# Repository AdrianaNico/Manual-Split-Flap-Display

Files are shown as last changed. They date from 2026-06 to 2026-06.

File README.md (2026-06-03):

# Manual Split-Flap Display
Welcome to the Manual Split-Flap Display project! Below you can see the 3D models and the physical prototype of this fully mechanical design. **Please note that in some renders and CAD screenshots, only 2 flaps are shown for demonstration purposes to allow a clearer view of the internal mechanism. The final, complete assembly contains all 10 flaps.**

| | |
|:---:|:---:|
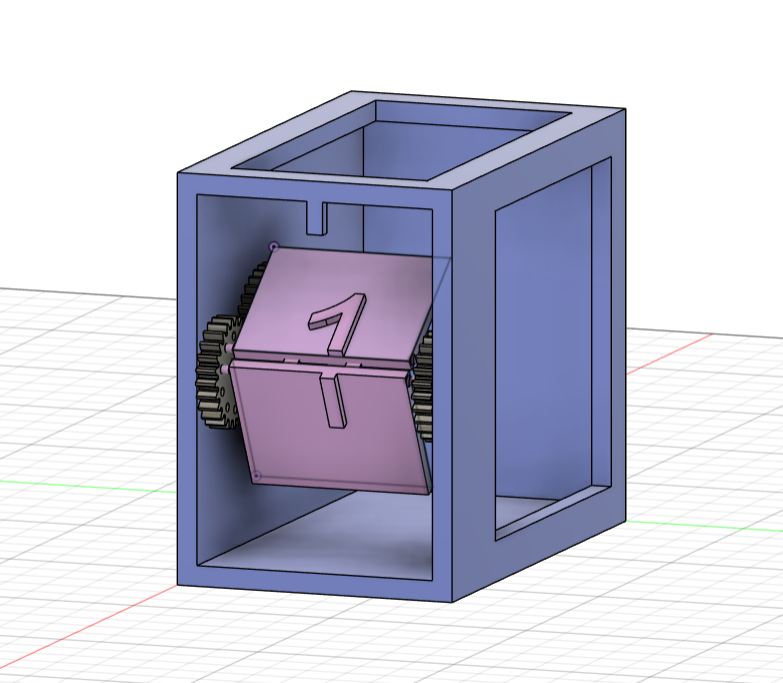
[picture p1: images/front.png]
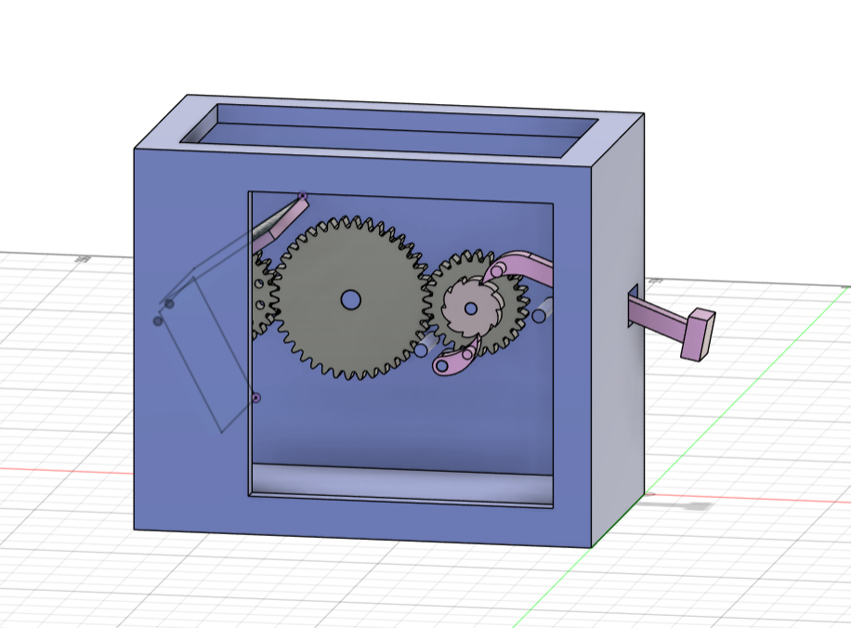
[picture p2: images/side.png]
|  |  |
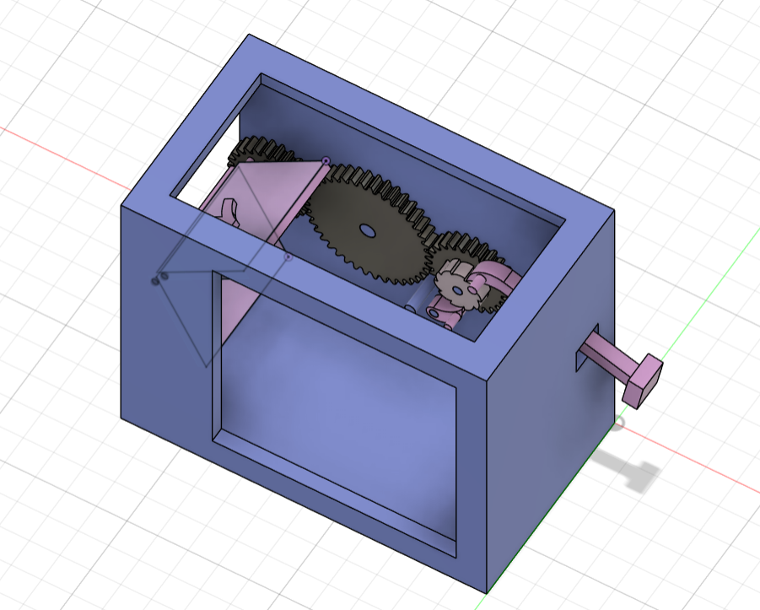
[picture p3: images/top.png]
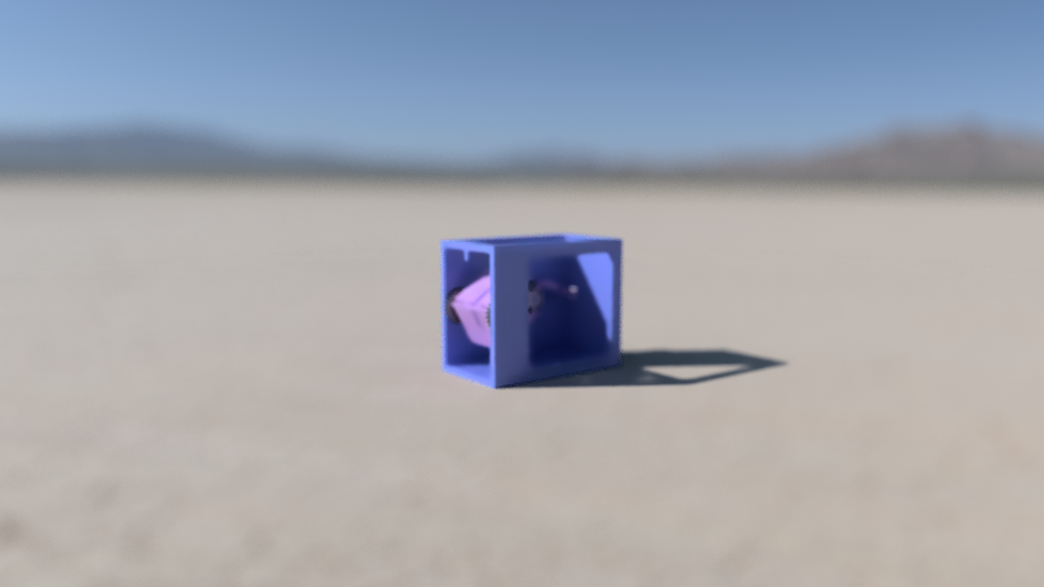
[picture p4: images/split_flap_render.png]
Split-Flap Display
|  |  |

🎥 **Project Video:** (https://youtu.be/XYKOU2_SeqI)

---

## Project Idea

This project consists of a manually operated split-flap display inspired by old train station and airport information boards.
The mechanism is designed entirely in Fusion 360 and optimized for 3D printing.
Instead of using motors or electronics, the display advances manually through a push-button mechanism that flips the next panel each time the button is pressed.

The display features:
* Numbers from 0 to 10
* A mechanical indexing and flipping system
* A compact, fully 3D printable assembly

---

## How It Works

The project uses a rotating drum containing multiple flaps. Each flap has a printed number or symbol.
When the user presses the button:
1. The kinematic mechanism rotates by a fixed angle (one full step).
2. The current flap is released from the stopper and falls forward.
3. The next number becomes visible and is locked in a perfectly vertical position.

---

## Objectives

* Design a functional split-flap mechanism in Fusion 360
* Create 3D components optimized for printing tolerances
* Implement a reliable manual step-by-step flipping mechanism
* Minimize the number of non-printable components
* Achieve precise and repeatable flap alignment

---

## Technical Details

* **Printing Material:** PETG, chosen for its mechanical wear resistance and the necessary flexibility for components under tension.
* **Project Structure (CAD):** Each component was modeled individually using a *Part Design* approach. The final project was consolidated into an *Assembly Design* to validate geometric constraints and kinematics by precisely defining motion joints.

---

## Main Components List

1. Main gear
2. Second gear
3. Third gear
4. Ratchet
5. Pawl
6. Arm button
7. Flap
8. Case

---

## Component Descriptions

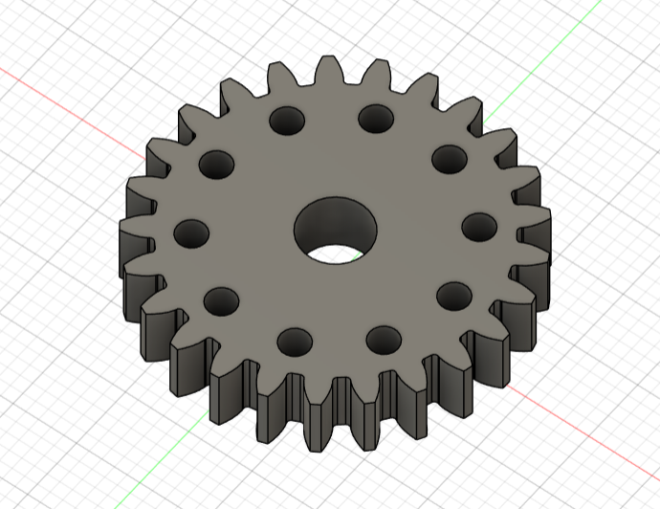
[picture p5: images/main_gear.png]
Main Gear Placeholder
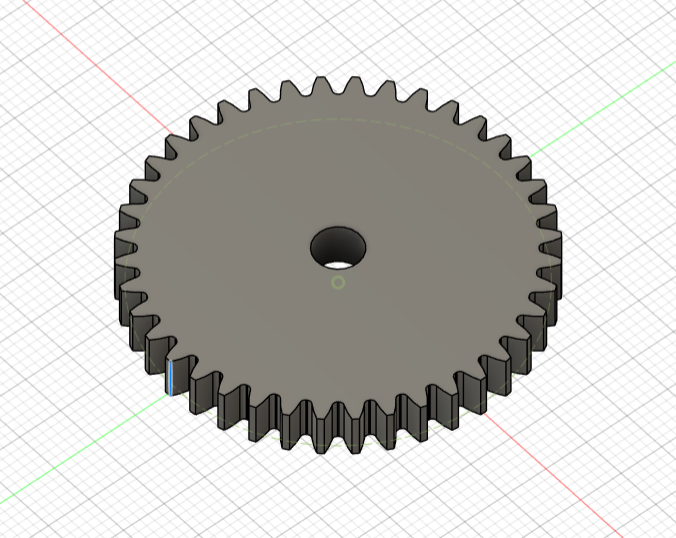
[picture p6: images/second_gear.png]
Second Gear Placeholder
|  |  |
|:---:|:---:|
| **Main Gear:** A primary gear equipped with 25 teeth for transmitting rotational motion. The structure integrates 10 radial slots spaced at equal angles, used as mounting and rotation points for the flap axes. | **Second Gear:** A 40-tooth intermediate gear responsible for transferring mechanical torque from the *third gear* to the *main gear*. The transmission ratio is strictly defined to ensure an exact 36-degree rotation per actuation (the angle required to sequentially index the 10 flaps). |

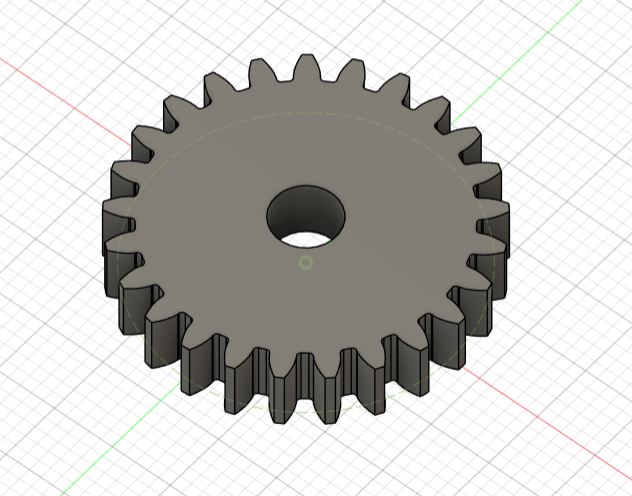
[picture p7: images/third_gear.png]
Third Gear Placeholder
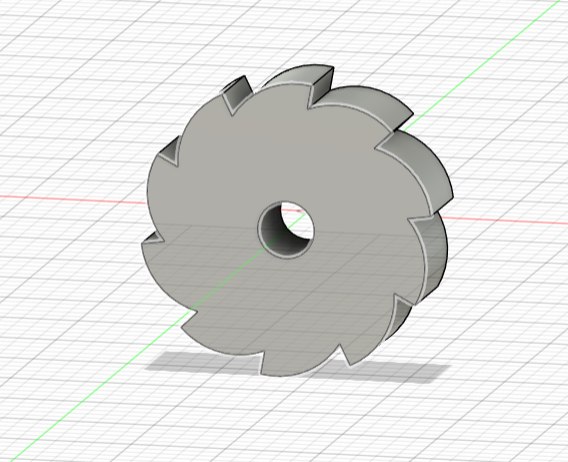
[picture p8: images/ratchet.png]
Ratchet Placeholder
|  |  |
|:---:|:---:|
| **Third Gear:** A motion take-up gear with identical specifications to the *main gear*, but with a solid structure lacking radial slots. It functions as a mounting base and provides a rigid coupling to the ratchet mechanism. | **Ratchet:** A ratchet wheel featuring asymmetrical teeth. Its kinematic role is to convert the linear motion of the actuating lever into unidirectional rotational motion. |

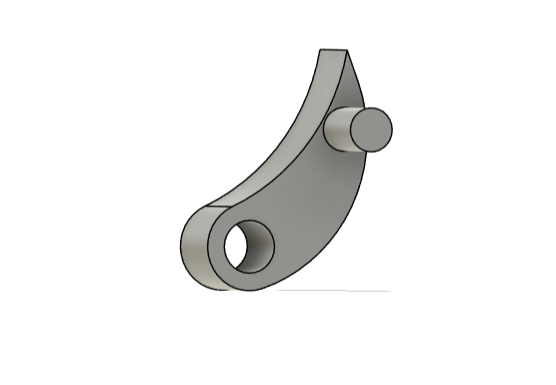
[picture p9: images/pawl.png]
Pawl Placeholder
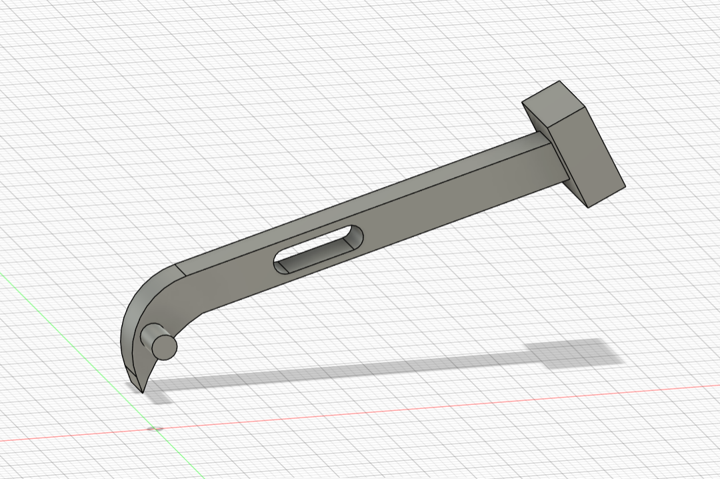
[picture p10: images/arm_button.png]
Arm Button Placeholder
|  |  |
|:---:|:---:|
| **Pawl:** A locking and retaining detent. It acts as a travel limiter for the *ratchet*, preventing over-travel and ensuring the actuating arm retracts only after reaching the optimal angle for releasing a single flap. | **Arm Button:** A linear actuating lever that includes an interactive toothed section (rack) to engage the *ratchet*. The operable end is designed as a detachable piece, allowing the shaft to pass through the guide holes in the case during assembly. |

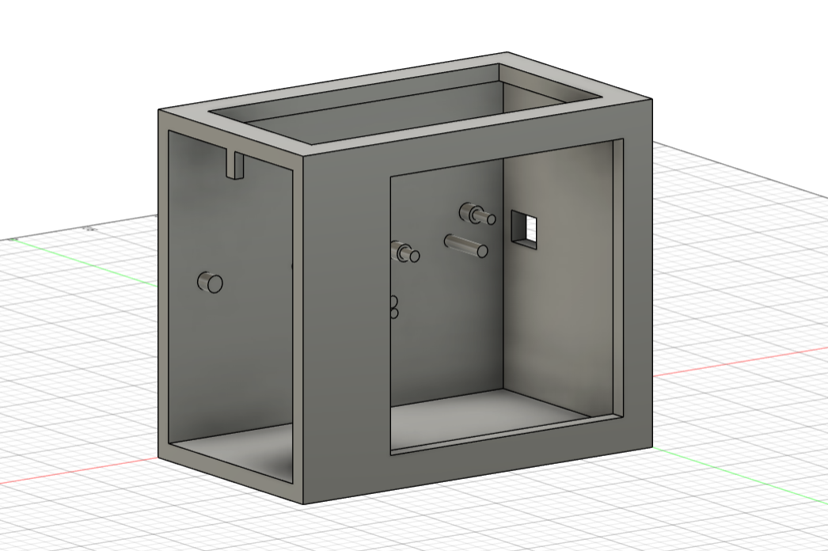
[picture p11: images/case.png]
Case Placeholder
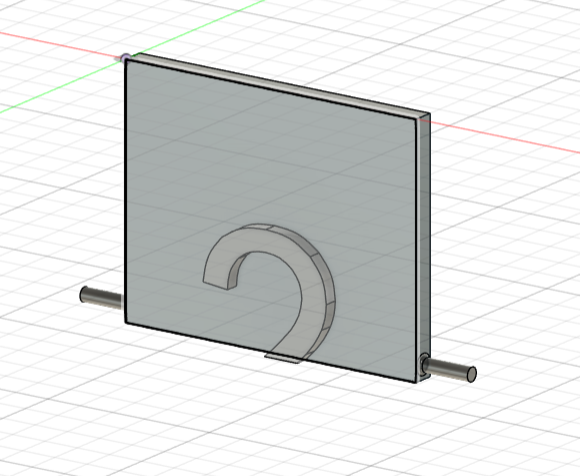
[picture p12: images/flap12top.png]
Flap Top
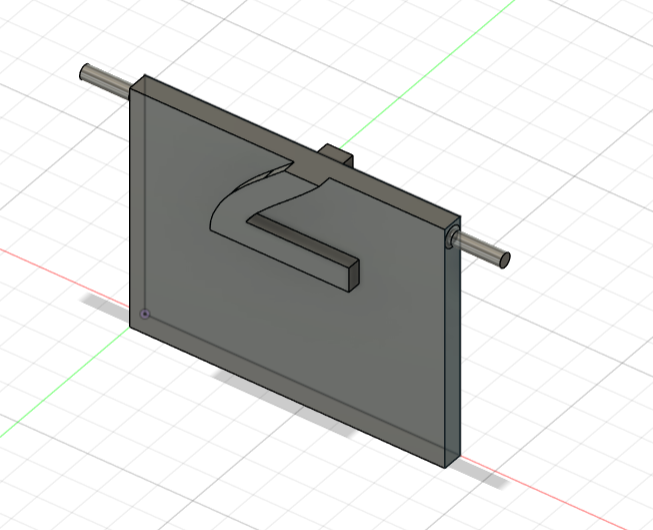
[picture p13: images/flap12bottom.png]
Flap Bottom
|  |   |
|:---:|:---:|
| **Case:** The load-bearing structure of the assembly. It integrates the bearings supporting the rotational axes of all moving parts. The design includes a geometric profile (stopper) placed in the upper section, calculated to support and lock the active flap in a vertical position. | **Flap:** A rectangular panel featuring pivots at its extremities for mechanical anchoring in the slots of the *main gear*. |

---

## Personal Touch

This project distinguishes itself from most split-flap implementations through its purely mechanical trigger approach, eliminating the reliance on electronic actuators, development boards (such as Arduino), and stepper motors found in standard models. 

The case was optimized with structural cutouts that expose the internal mechanical architecture, allowing direct observation of the gear kinematics during indexing. Furthermore, during the Fusion 360 design phase, the kinematic analysis was refined by configuring advanced motion constraints (Contact Sets and Motion Links). This allowed me to dynamically simulate the elasticity introduced by the restoring force of the tensioning rubber bands on the *pawl* system and the actuating lever.

---

## Non-Printable Objects

To complete the mechanical functionality of the system, a few external elements were required:
* **Tensioning Rubber Bands:** Small elastic bands integrated into the system to provide the necessary restoring force (return spring). They are used to bring the *arm button* back to its initial position after a press, and to maintain constant contact pressure from the *pawl* against the toothed surface of the *ratchet*.

---

## Tools Used

* Fusion 360
* GitHub
* 3D Printer
* PrusaSlicer

---

## References

* Split-flap display mechanism inspiration
* Vintage airport/train station displays
* [Fully 3D Printed Split Flap Display - Reddit](https://www.reddit.com/r/3Dprinting/comments/1jeub4g/i_designed_a_split_flap_display_fully_3d_printed/)
* [Mechanical Split Flap Inspiration - Instagram](https://www.instagram.com/p/BsODiyCHwc7/?utm_source=ig_web_copy_link&igsh=NTc4MTIwNjQ2YQ==)

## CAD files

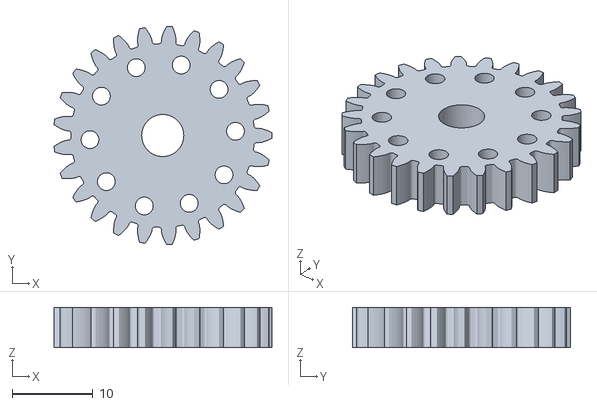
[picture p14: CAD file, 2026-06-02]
Fusion360/.stl Files/Main gear.stl
26.9 x 27.0 x 5.00

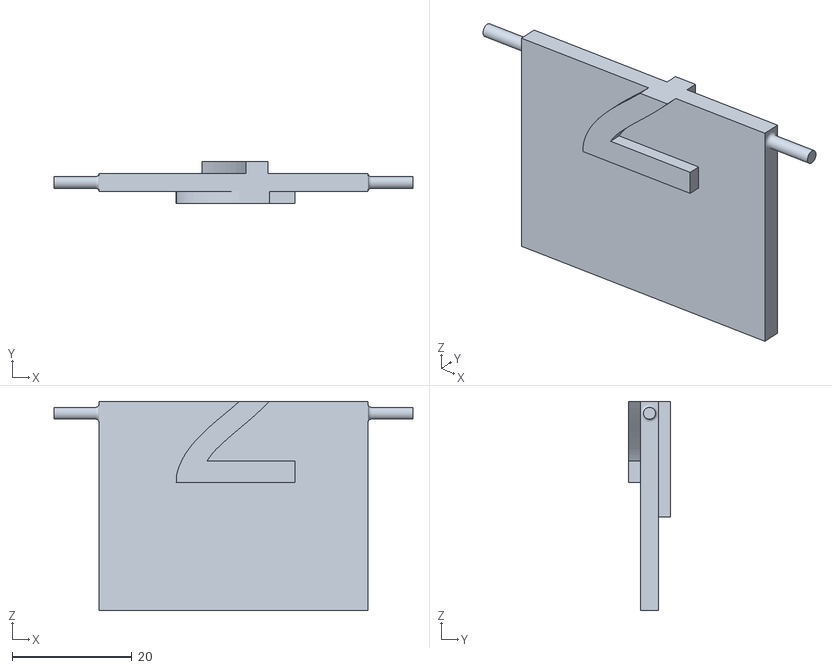
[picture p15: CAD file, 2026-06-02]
Fusion360/.stl Files/Flap12.stl
60.0 x 7.00 x 35.0

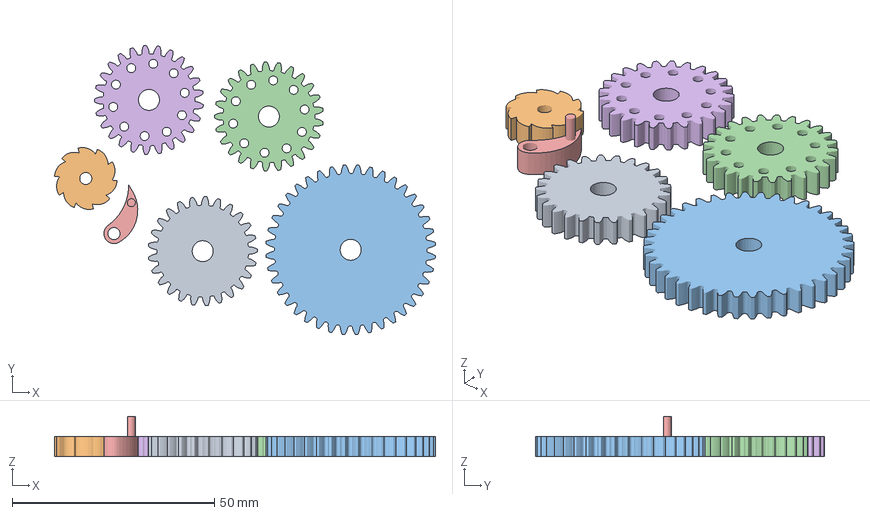
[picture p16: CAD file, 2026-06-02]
Fusion360/GCODE Files/Gears and pawl.3mf
94.2 x 71.5 x 10.0 mm
Split flap display.stl_2
Split flap display.stl_3
Split flap display.stl_4
Split flap display.stl_5
Split flap display.stl_6
Split flap display.stl_8

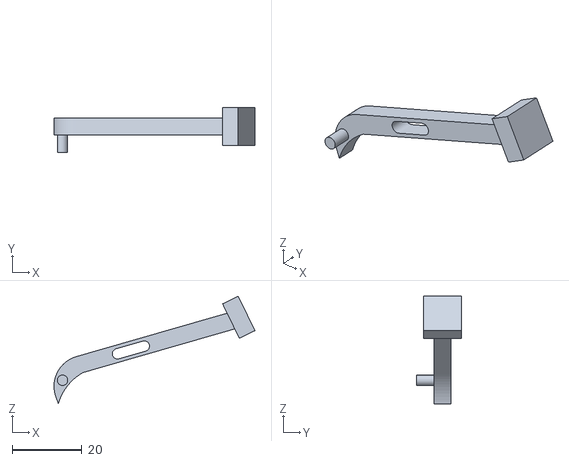
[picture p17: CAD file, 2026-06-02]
Fusion360/.stl Files/Arm button.stl
57.8 x 13.0 x 30.9

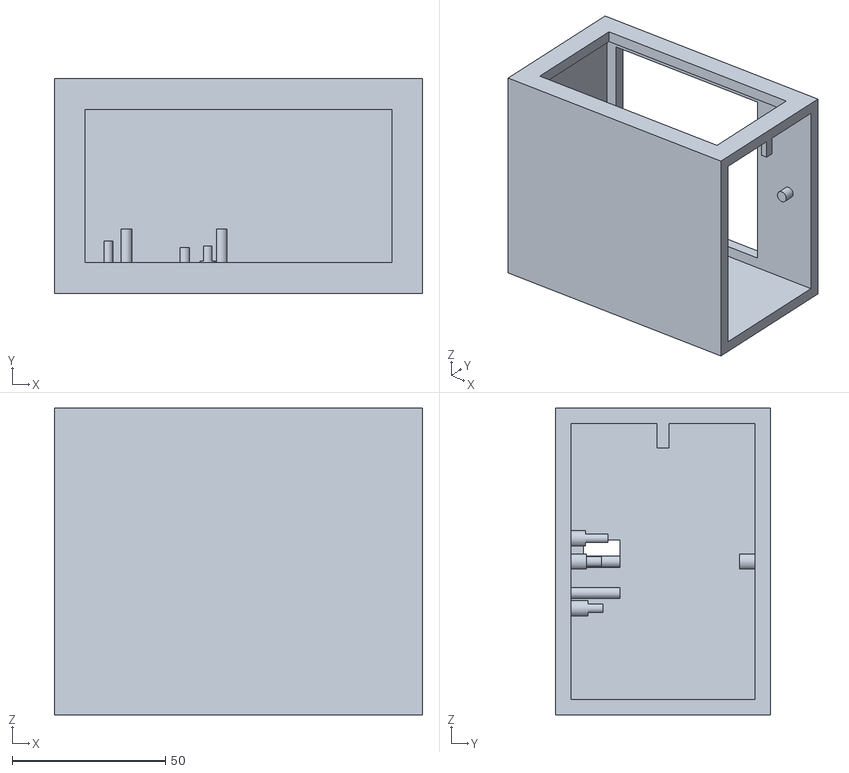
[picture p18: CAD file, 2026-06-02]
Fusion360/.stl Files/Case.stl
120.0 x 70.0 x 100.0

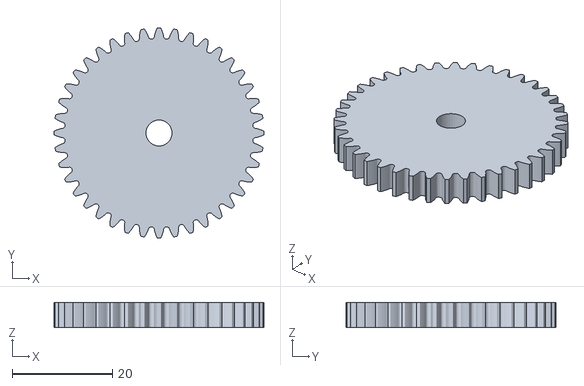
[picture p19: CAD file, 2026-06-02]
Fusion360/.stl Files/Second gear.stl
42.0 x 42.0 x 5.00

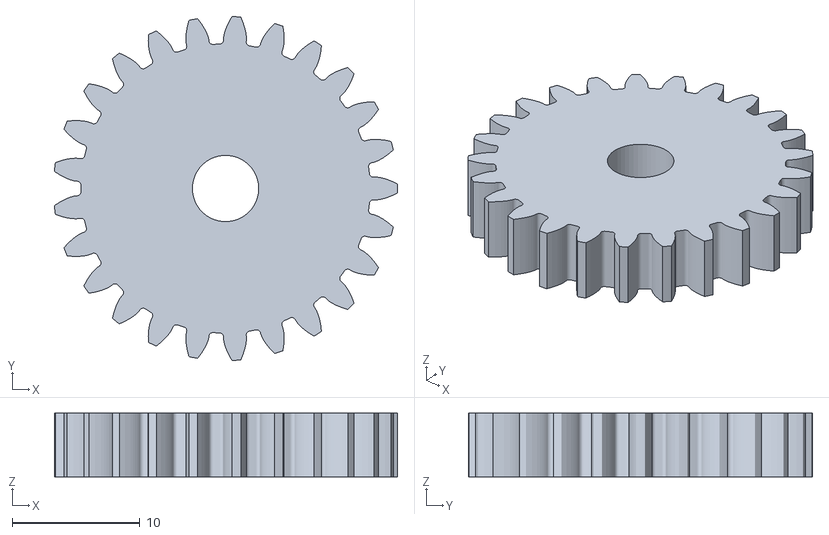
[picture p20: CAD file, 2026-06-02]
Fusion360/.stl Files/Third gear.stl
26.9 x 27.0 x 5.00

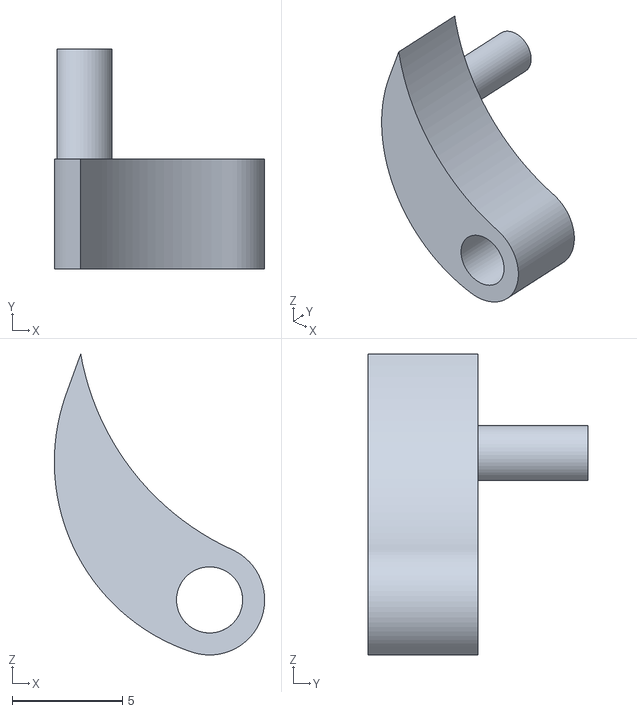
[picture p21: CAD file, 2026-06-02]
Fusion360/.stl Files/Pawl.stl
9.54 x 10.0 x 13.7

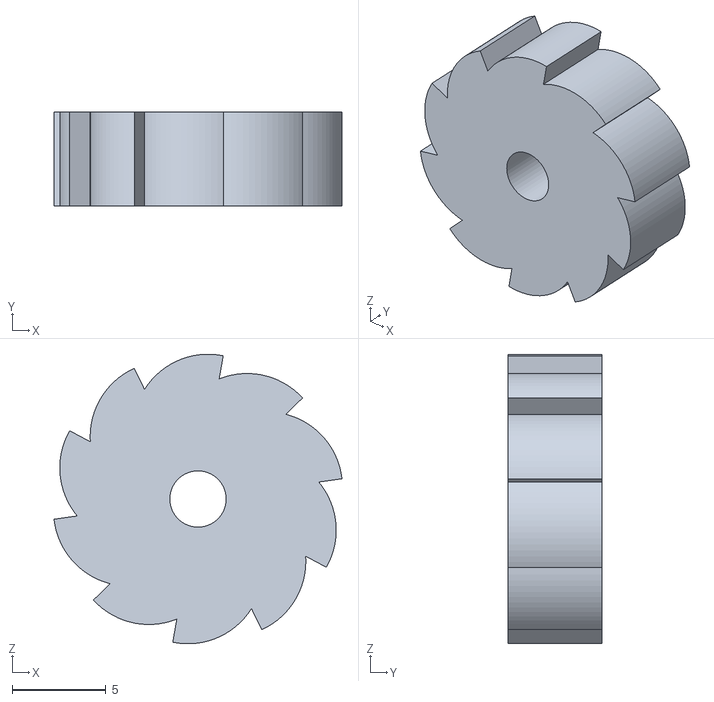
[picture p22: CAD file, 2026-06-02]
Fusion360/.stl Files/Ratchet.stl
15.3 x 5.00 x 15.4

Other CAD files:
Fusion360/.stl Files/Flap01.stl
Fusion360/.f3d Files/Arm button.f3d
Fusion360/.f3d Files/Case.f3d
Fusion360/.f3d Files/Flap01.f3d
Fusion360/.f3d Files/Flap12.f3d
Fusion360/.f3d Files/Main gear.f3d
Fusion360/.f3d Files/Pawl.f3d
Fusion360/.f3d Files/Ratchet.f3d
Fusion360/.f3d Files/Second gear.f3d
Fusion360/.f3d Files/Third gear.f3d

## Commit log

2026-06-02 Add case.stl file to Fusion360 directory
    [case.stl]
2026-06-03 Rename main gear.png to main_gear.png
2026-06-03 Rename arm button.png to arm_button.png
2026-06-03 Rename second gear.png to second_gear.png
2026-06-03 Rename third gear.png to third_gear.png
